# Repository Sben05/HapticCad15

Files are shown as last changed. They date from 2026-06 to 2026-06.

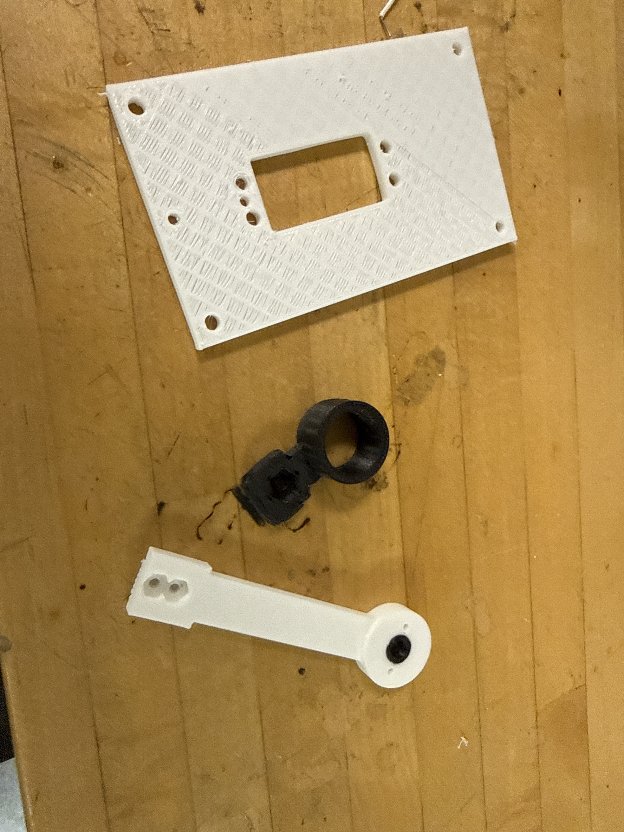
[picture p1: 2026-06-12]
image.jpg

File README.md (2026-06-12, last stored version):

# ME433 HW15 - Haptic Paddle, mechanical first draft
Shreeniket Bendre

Five printable parts, generated parametrically from `haptic_paddle.py`
(CadQuery). STLs are ready to slice; STEP files import into Onshape,
Fusion, or SolidWorks if you want to edit visually.

## Parts
| File | What it is | Hardware it touches |
|---|---|---|
| paddle_arm | Lever arm, horn interface at one end, load cell clamp at the other | servo horn + 2 wood screws, 2x 4-40 screws + nuts |
| magnet_cap | Press-fits into the arm boss bore, covers the horn machine screw, holds the AS5600 magnet on the rotation axis | 6 x 2.5 mm diametric magnet (glue) |
| thimble_clamp | Clamps the free end of the load cell, finger ring | 1x 8-32 screw + nut |
| base_plate | Servo drops into the cutout, flange bolts down with the rubber dampers | 4x 8-32 |
| as5600_bracket | Column + cantilever holding the AS5600 board chip-down over the magnet | 2x M3 to plate, 2x M3 into standoffs |

## MEASURE BEFORE PRINTING (calipers, 5 minutes, saves 3 reprints)
Every one of these is a named parameter at the top of haptic_paddle.py:
1. Load cell: width, height, hole positions from the end, and hole size.
   Defaults assume a TAL221-style 45 x 10 x 6 mm mini cell.
2. Servo: body cutout length/width, flange hole spacing (dx, dy),
   and shaft offset from body center. Defaults are standard-size class.
3. Horn: diameter, thickness, wood-screw hole radius. Round horn assumed.
4. Magnet: diameter and thickness. Pocket has +0.25 mm glue clearance.
5. AS5600 board: mounting hole spacing (pcb_hole_dx). Defaults to 18 mm.
6. magnet_top_z: you can only measure this after the servo, horn, arm,
   and cap are assembled on the plate. Print the bracket LAST, after
   measuring, so the chip-to-magnet air gap lands at 1 to 2 mm.

## Print settings
PLA, 0.2 mm layers, 3 perimeters, 40 percent infill, no supports needed.
Orientations: arm and thimble flat with hex pockets facing UP. Cap with
magnet pocket UP (it bridges the screw bore internally, that is fine).
Plate flat. Bracket lying on its SIDE with a brim, not standing.

## Assembly order and the professor's gotchas
1. Servo into plate with dampers and 8-32s. Horn on spline, machine screw.
2. Arm onto horn: the horn nests in the recess under the boss. The wood
   screws WILL be too long (prof's lesson). Run them in from the top and
   check the tips do not protrude past the horn; add washers under the
   heads or trim the screws. Mind the pinch point while the servo moves.
3. Press the magnet_cap into the boss bore (9.4 into 9.5: FDM holes print
   slightly undersized, so this should be a firm press fit; sand the cap
   OD lightly if too tight). Glue the magnet in its pocket.
4. Load cell under the arm pad, 2x 4-40 up through the cell into the hex
   nut pockets on top. Thimble on the other end with the 8-32 the same way.
   Keep the load direction tangential to the single-screw clamp.
5. Measure magnet_top_z, set it in the script, regenerate, print bracket,
   bolt it down, mount the AS5600 chip-side DOWN on the standoffs.

## Known first-draft weaknesses (expect to iterate, like the prof says)
- The bracket cantilever is unsupported plastic about 50 mm long; if the
  sensor reading is noisy from vibration, add a rib or a second column.
- The thimble ring is a closed circle, ID 19 mm. Measure your finger.
- Backlash: the servo gear train has about a degree of slop (prof's
  lesson 6); the AS5600 reads the OUTPUT side of that, which is the
  point of mounting the encoder on the horn axis instead of trusting
  the servo's internal pot.

## Regenerating
pip install cadquery
python3 haptic_paddle.py
STLs land in stl/, STEPs in step/.

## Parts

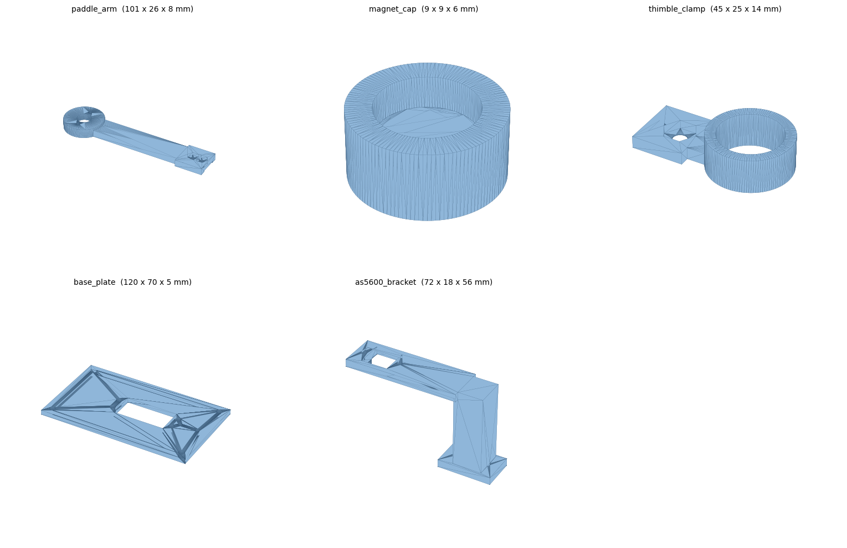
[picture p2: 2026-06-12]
parts_preview.png

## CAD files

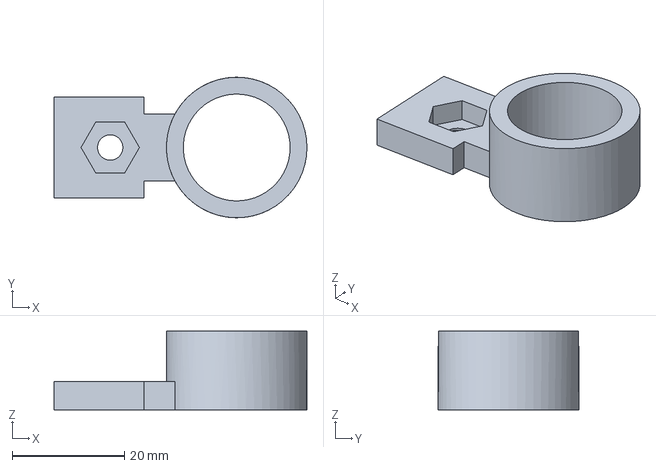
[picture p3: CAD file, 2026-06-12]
step/thimble_clamp.step
45.0 x 25.0 x 14.0 mm

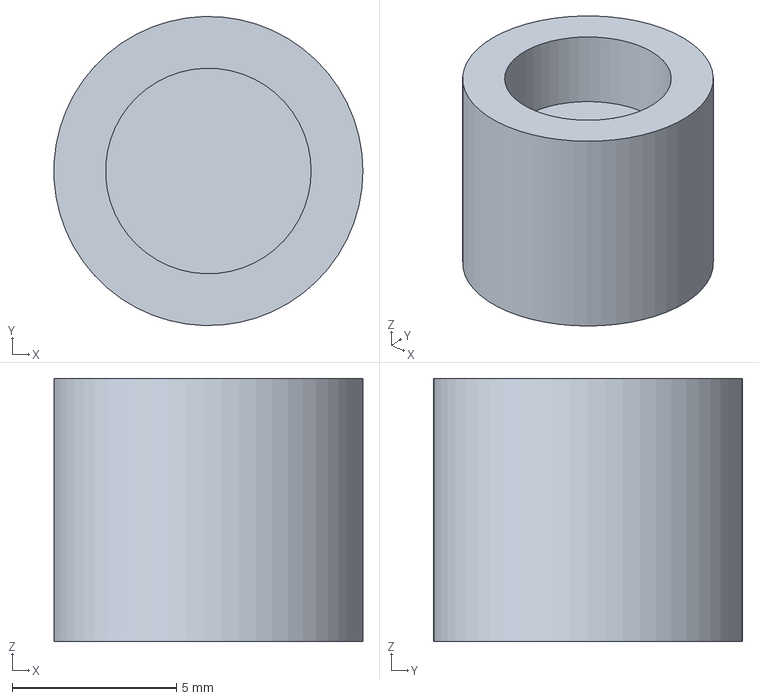
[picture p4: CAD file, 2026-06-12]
step/magnet_cap.step
9.39 x 9.40 x 8.00 mm

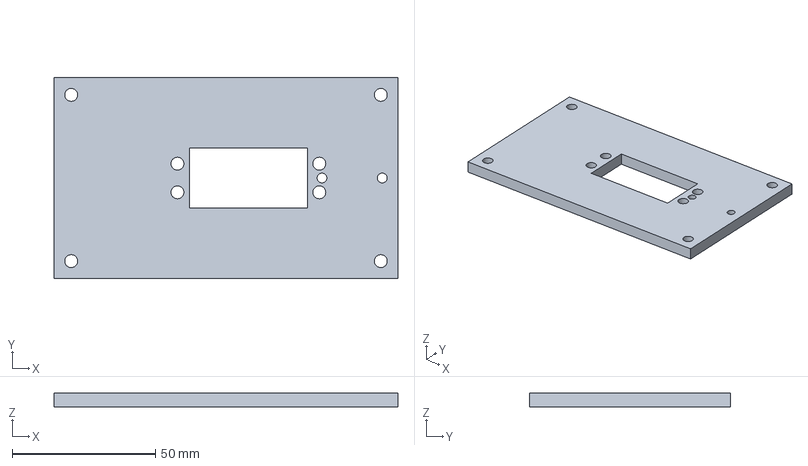
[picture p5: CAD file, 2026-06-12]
step/base_plate.step
120.0 x 70.0 x 5.00 mm

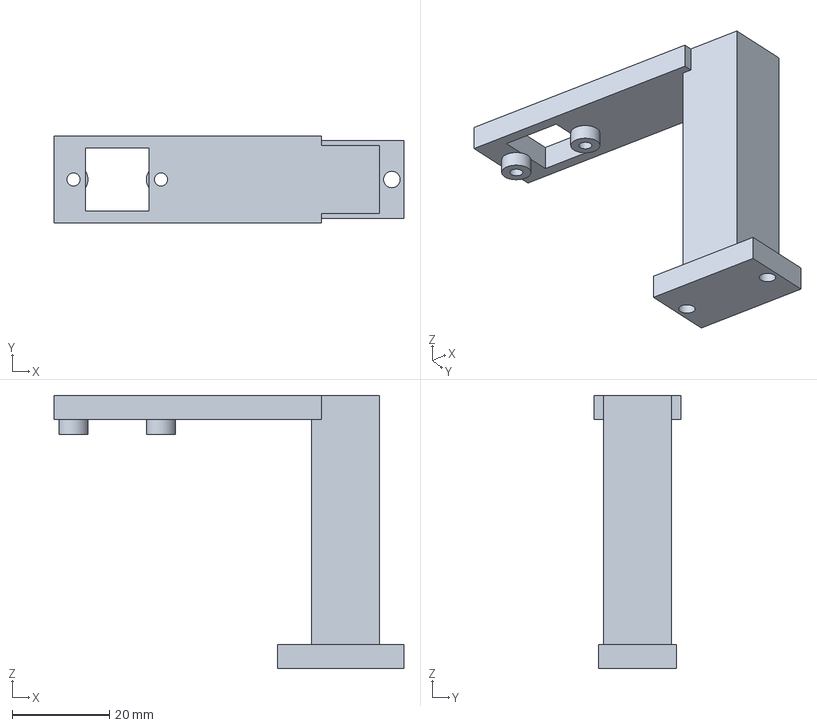
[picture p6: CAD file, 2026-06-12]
step/as5600_bracket.step
72.0 x 18.0 x 56.2 mm

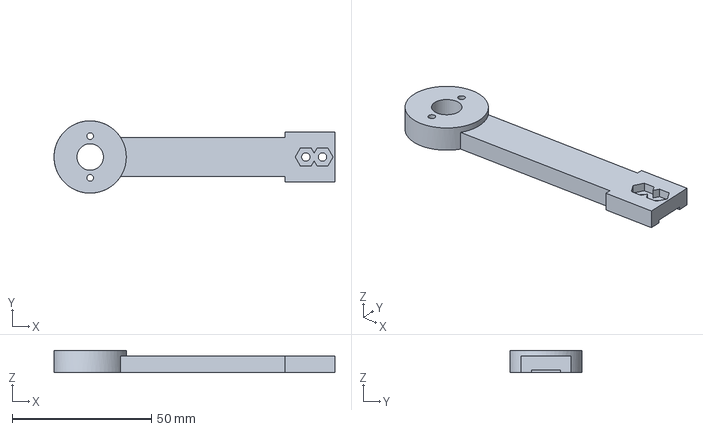
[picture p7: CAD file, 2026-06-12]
step/paddle_arm.step
101.0 x 26.0 x 8.00 mm

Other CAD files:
stl/as5600_bracket.stl
stl/base_plate.stl
stl/magnet_cap.stl
stl/paddle_arm.stl
stl/thimble_clamp.stl
